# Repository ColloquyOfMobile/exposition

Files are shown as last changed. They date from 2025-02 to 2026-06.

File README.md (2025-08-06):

# exposition
Colloquy of Mobiles for exposition in ZKM

## Todo
In KiCad:
- Choose the footprint for power supply capacitor.
- Check dimension of jack barrel.

## Todo

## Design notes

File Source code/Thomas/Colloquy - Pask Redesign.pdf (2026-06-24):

ZKM | Zentrum für Kunst und Medien

# Gordon Pask – Colloquy of Mobiles

Redesign of 2018 Version

Thomas Erforth
23.6.2026

## Audio subsystem concept

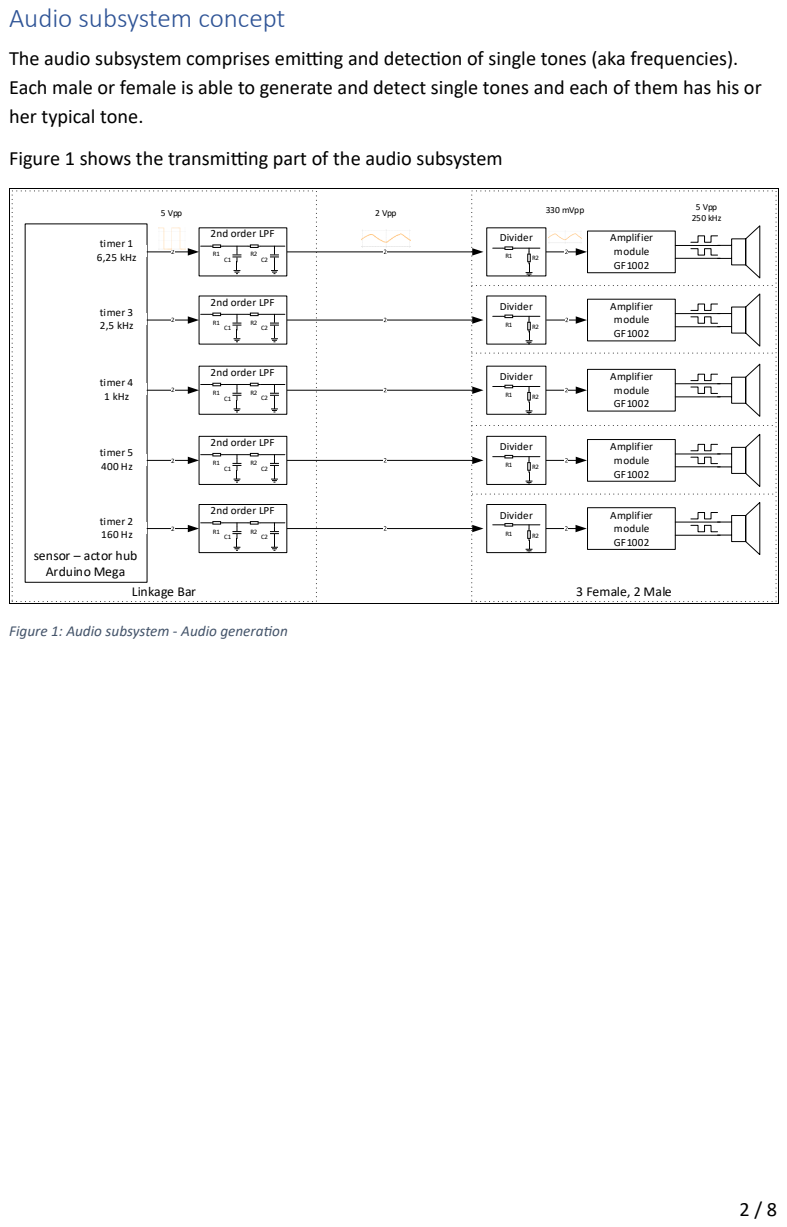
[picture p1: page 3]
timer 1 6,25 kHz; Amplifier module GF1002; timer 3 2,5 kHz; timer 4 1 kHz; timer 5 400 Hz; timer 2 160 Hz; 5 Vpp; 2 Vpp; 330 mVpp; Linkage Bar; 3 Female, 2 Male; 5 Vpp 250 kHz; 2nd order LPF; Divider

The audio subsystem comprises emitting and detection of single tones (aka frequencies).
Each male or female is able to generate and detect single tones and each of them has his or
her typical tone.

Figure 1 shows the transmitting part of the audio subsystem

sensor – actor hub
Arduino Mega

Figure 1: Audio subsystem - Audio generation

Figure 2 shows the receiving part of the audio subsystem

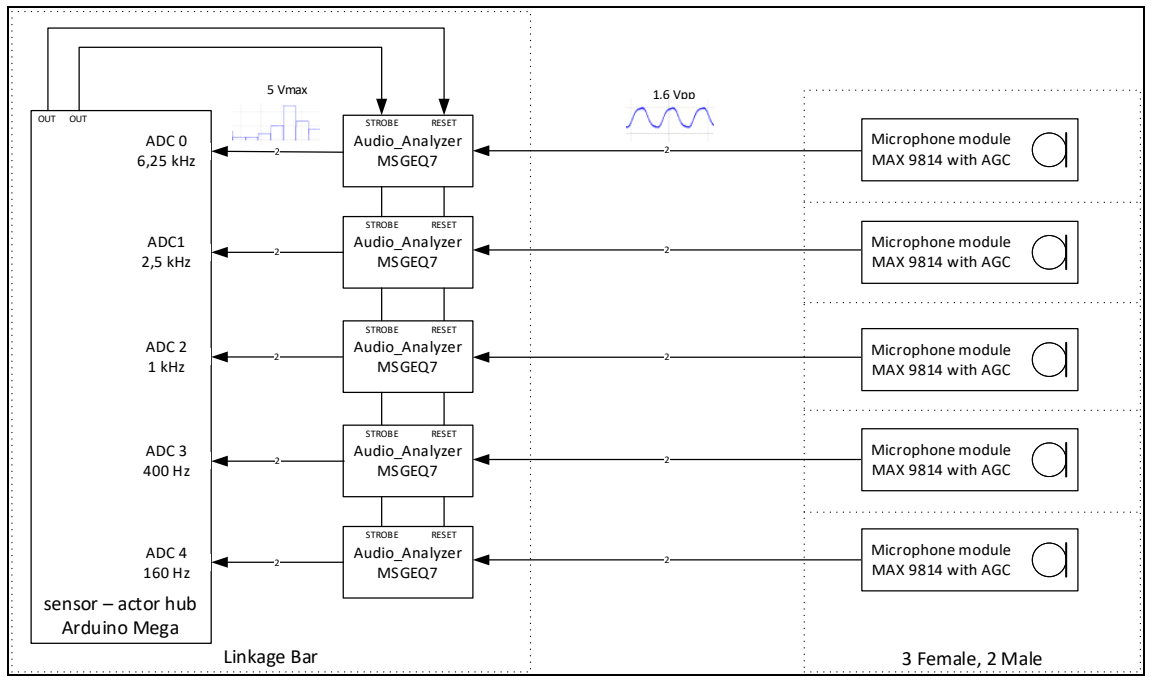
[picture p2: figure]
sensor – actor hub Arduino Mega; ADC 0 6,25 kHz; Audio_Analyzer MSGEQ7; Microphone module MAX 9814 with AGC; ADC1 2,5 kHz; ADC 2 1 kHz; ADC 3 400 Hz; ADC 4 160 Hz; 5 Vmax; 1,6 Vpp; Linkage Bar; 3 Female, 2 Male; STROBE; RESET; OUT

Figure 2: audio subsystem - Audio detection

In the following the structure of the audio subsystem and the design decisions are explained in more detail.

Audio generation and transmission

Tone generation
The audio analyzer module used for tone detection supports up to seven frequency bands: 63 Hz, 160 Hz, 400 Hz, 1KHz, 2.5 kHz, 6.25 kHz and 16 kHz.

Due to limitations in the frequency response of the components involved the 63 Hz and 16 kHz bands are of no choice. For example, typical electret microphones are specified in the frequency range of 100 Hz – 10000 Hz. And in addition, probably a significant amount of the audience will not even be able to hear the 16 kHz band anyway.

Since the ZKM concept uses a centralized sensor / actor hub the remaining five tones are generated by the Arduino Mega board. Timer 1, 3, 4, 5 (16-bit timers) and 2 (8-bit timer) are used for that purpose. With exception of the initialization, tone generation doesn’t consume computing power since all timers run independently in CTC mode.

Low Pass Filter
Generating tones by means of counters makes life easier but has a big drawback: The result has a rectangular shape. Square waves can be thought of as the superposition of sine waves, starting with the fundamental frequency plus all odd harmonics. Especially for the first three frequency bands the bandpass filters of the audio analyzer are not able to completely filter out the first harmonic, see Table 1. This makes it much more difficult to safely detect the incoming fundamental frequency, especially in a noisy environment.
Square wave freq. | 1 st harmonics | Neighbor band | Distance
160 Hz | 480 Hz | 400 Hz | 80 Hz
400 Hz | 1200 Hz | 1000 Hz | 200 Hz
1000 Hz | 3000 Hz | 2500 kHz | 500 Hz
2500 Hz | 7500 kHz | 6250k Hz | 1250 Hz
6250 Hz | 18750 Hz | 16000 Hz | 2750 Hz
Table 1: Frequency bands and their first harmonics

The best solution would be generating sine waves only. This is not feasible with the centralized computing concept since it will block the CPU of the hub during tone generation. Therefore, it has been decided to use simple passive 2nd order low pass filter stages to damp the first and subsequent harmonics sufficiently enough to improve the quality of the frequency detection. Figure 3 shows the principal diagram of the second order filter.

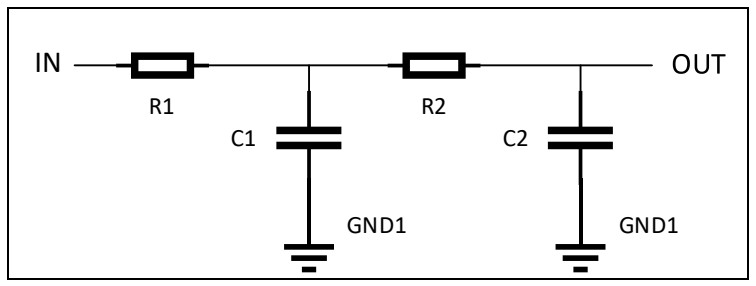
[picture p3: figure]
GND1

Figure 3: Passive 2nd order low pass filter

The output of the filter is still not a sine wave but measurements have shown the first harmonic damped by more than 20 dB = less than 10% to the fundamental frequency.

To simplify the design the two filter stages are identical, R1 = R2 and C1 = C2.

The following component values are used:

Band | R | C
6250 Hz | 2K2 | 10nF
2500 Hz | 1K8 | 47nF
1000 Hz | 1K2 | 150nF
400Hz | 2K | 220nF
160 Hz | 2K2 | 470nF
Table 2: Filter component values

It has been decided, while not necessarily needed for safe frequency detection, to add filter stages to the upper two frequency bands to achieve a more pleasant and uniform sound experience in all frequency bands.

Input divider
A potential divider is used to limit the filter output to the maximum allowed input level of the amplifier module when the volume control of the module is set to maximum level. The filter stages are dimensioned in a way to get identical component values for all five dividers: R1 / R2 = 22K / 3K3.

It is important never to exceed the maximum input level of the amplifier, otherwise it would go into clipping which results in a square wave output on the loudspeaker. This would render the filter stage useless.

Amplifier
The amplifier used is a GF 1002 module. It comes with volume level control included on the module which allows for further adjustments of the tone level later during field tests.

The amplifier is a class D design which means the output to the loudspeaker is formed by a differential PWM signal with approx. 250 kHz base frequency. The sharp edges and the high currents generate significant EMI emissions; therefore, the amplifier shall be placed close to the loudspeaker to keep the connection wires as short as possible.

Loudspeaker
The loudspeaker must be able to produce a flat frequency response over the range of 160 Hz up to 6250 Hz.

If the existing speakers fit the requirement needs to be tested. The speakers are mounted in an open frame and are working more or less in an acoustic short cut situation. Especially for the two lower frequencies it must be tested if the sound pressure is sufficient.

Audio detection

Microphone module
The 2018 version uses a microphone module with a simple OpAmp pre amplifier. There is a high probability that such a simple module will be overloaded in a noisy environment. The pre amplifier will go into saturation and output the tone as a square wave. Detecting the fundamental becomes unreliable as described before.

Instead, the concept foresees a microphone module with automatic gain control. Common modules carry the MAX9814. The device features a low-noise preamplifier, variable gain amplifier (VGA), output amplifier, microphone-bias-voltage generator and AGC control circuitry. AGC gives a lot more headroom to possible clipping situations.

In addition, the gain can be selected manually to 40dB, 50dB or 60dB. On the workbench best results were achieved with gain limited to 40dB and A/R ratio set to 1:500. With A/R ratio 1:500 the gain recovers fastest after spikes. Must be double checked in field.

Audio analyzer
The audio analyzer circuit MSGEQ7 has already been used in the 2018 version of the ‘Mobile’, so no change here.

Theoretically a small computing module could be used to perform a simple Fourier analysis however, implementing and debugging the code adds an additional level of complexity which would increase development time. With the described countermeasures of filtering and AGC it should be possible to reliably detect the fundamental frequency with the audio analyzer module.

The STROBE and RESET inputs of the audio analyzer modules are all connected together to spare port resources on the hub. One cycle over all seven bands will read the outputs of all modules at the same time. The analog outputs are connected to five ADC inputs of the hub.

One property of the MSGEQ7 must be considered during programming: The internal scan rate is fast enough to take dedicated samples from the curve of the 160 Hz and 400 Hz signals. So, continuous readings with a certain amount of time in-between will show varying results depending on which part of the signal shape has been measured. This problem could be solved by reading four times in short sequence when a 160 Hz signal and two times in a sequence when a 400 Hz signal is expected. The results for the 160 Hz input always showed at least two ‘hits’ of high input levels and the 400 Hz at least one. (Will need some more experiments in the field test.)

Prototype boards

For first tests some prototype boards have been designed. Figure 4 - Figure 7 show the pinout.

Low Pass Filter

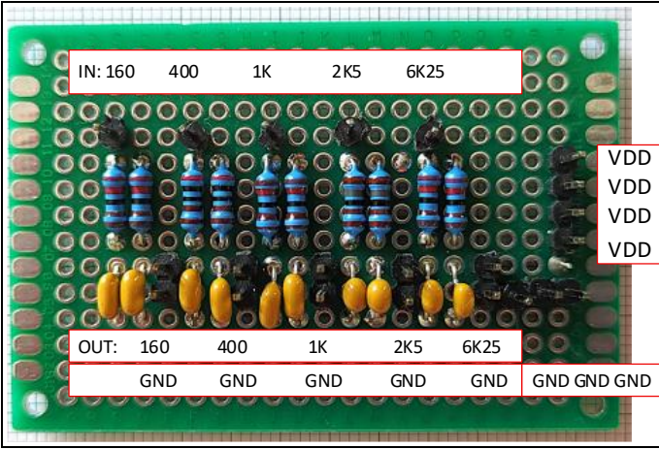
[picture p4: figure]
OUT: 160; GND; GND GND GND; VDD VDD VDD VDD

Figure 4: Filter module pinout

Microphone Module

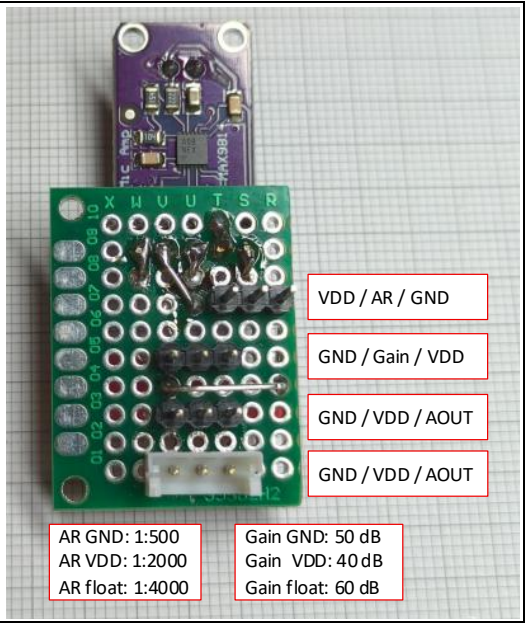
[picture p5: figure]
GND / VDD / AOUT; GND / Gain / VDD; VDD / AR / GND; AR GND: 1:500 AR VDD: 1:2000 AR float: 1:4000; Gain GND: 50 dB Gain VDD: 40 dB Gain float: 60 dB

Figure 5: Microphone module pinout

Amplifier Module

Audio
GND

Audio
VDD
GND

VDD
GND

ROUT+
ROUT-

ROUT+ / ROUT-

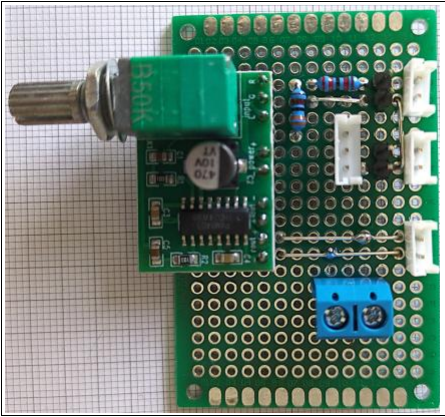
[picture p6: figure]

Figure 6: Amplifier module pinout

Audio Analyzer Array

AOUT

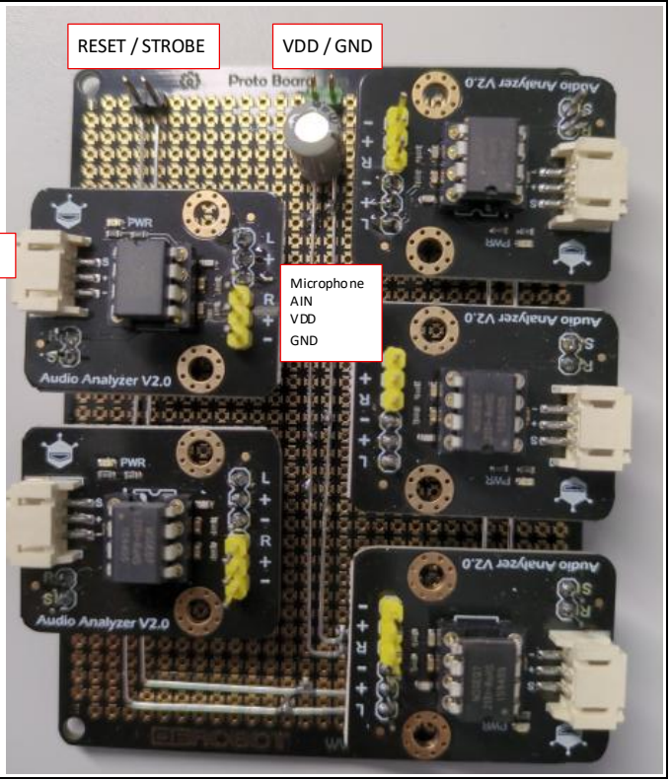
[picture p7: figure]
Microphone AIN VDD; GND; RESET / STROBE; VDD / GND

Figure 7: Audio analyzer array

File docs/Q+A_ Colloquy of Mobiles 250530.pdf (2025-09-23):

Q+A: Colloquy of Mobiles 250530
Victor, Morgan, Paul and TJ

### Question: Is the male/neopixel/ring always white ? (or matches drive color)

### Male neopixel ring color

The male has 2 neopixel rings. One displays drive level in white, this is above the unit and pointed toward the plinth. On system powerup, a reference pattern is briefly displayed across all neopixels that consists of a variety of colors. Once the system begins running, this neopixel ring is white and brightness varies.

The other is in the center of the unit and is white when searching, when it is reinforcing it has an animation one pixel of which shows drive state.

- Searching State - When the male is in a searching state, the NeoPixel ring appears white. This is determined by the act_update_drive_abso_light function, which sets the NeoPixel color to white when the drive state exceeds the other. For males, the brightness is set to a maximum of 128 when searching, resulting in a clear but not blinding white appearance.
- Reinforcing State - In contrast, during the reinforcing state, the NeoPixel ring animates to indicate the current drive state with a colored pixel. This is managed by the act_energy_driveanimation function, which illuminates one pixel to reflect the drive state—using orange for O and puce for P—while the remainder of the ring stays white and is set to maximum brightness.

Thomas J McLeish, May 30, 2025 page 1/9

### Question: How does drive level map to pixel brightness?

O drive max = 255 (max pixel brightness) ? O drive min = 0 (pixel shutdown) ? P drive max = 255 (max pixel brightness) ? P drive min = 0 (pixel shutdown) ?

### Perceptual Brightness Mapping for NeoPixels

The Colloquy of Mobiles 2018 implements perceptual brightness control for NeoPixels by mapping a linear input variable—drive level—to a non-linear brightness value that approximates the human eye’s response to light intensity. This is achieved through a fixed lookup table, allowing efficient real-time computation on resource-constrained microcontrollers.

Rationale

Human vision perceives brightness non-linearly. A linear increase in LED power does not result in a linear increase in perceived brightness. To address this, a non-linear brightness map is used, allowing small changes in brightness to be more noticeable in darker regions and less abrupt at higher intensities.

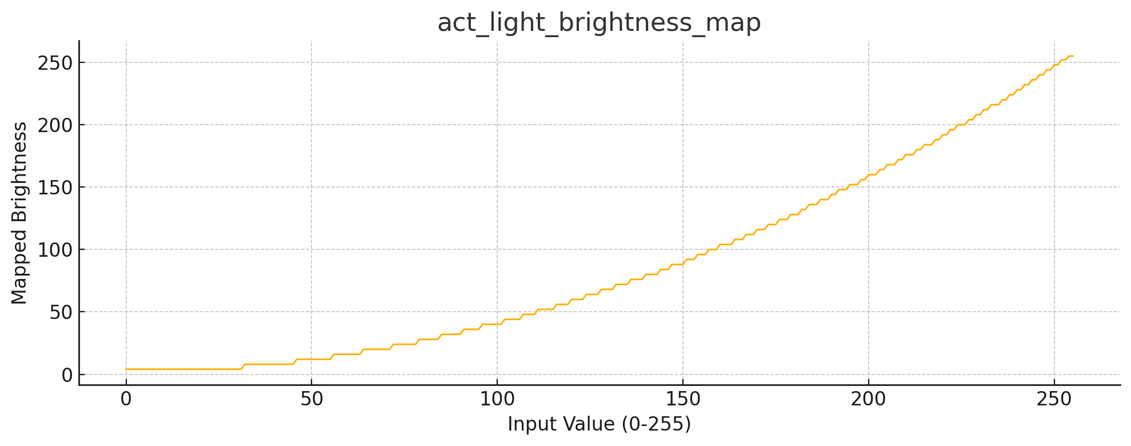
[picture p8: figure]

The human-perception brightness level is derived from an input value.

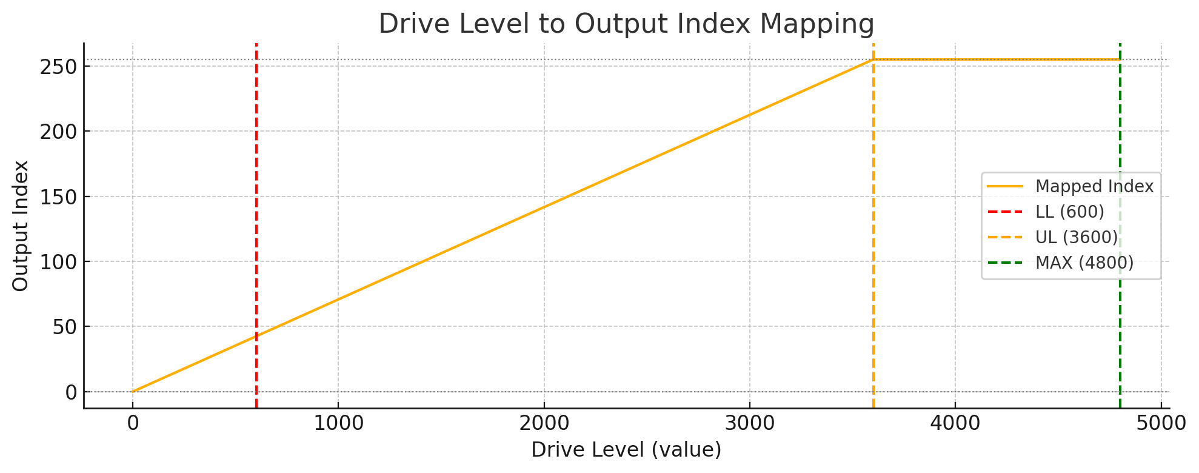
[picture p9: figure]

The input value is derived from the drive level.

See code:

// Drive level thresholds (in samples) const int internal_drive_LL = 600; // Low threshold (30 seconds)
const int internal_drive_UL = 3600; // High threshold (3 minutes)
const int internal_drive_MAX = 4800;
// Maximum (4 minutes)
const int internal_drive_adjustment_O = 1;
int | internal_drive_O = 0;
//set lights indicating
//level of O and P drive states act_update_O_light(constrain(map(internal _drive_O, 0, internal_drive_UL, 0, 255), 0, 255));
act_update_P_light(constrain(map(internal _drive_P, 0, internal_drive_UL, 0, 255), 0, 255));

### Question: What is the rate of drive level increment over time?

P drive increment X unit every Y seconds. X and Y ? O drive increment X unit every Y seconds. X and Y ?

### Drive Increment Rate per Time Unit

P drive increment: 1 unit every 50 ms
→ 20 units per second

O drive increment: 1 unit every 50 ms
→ 20 units per second
1. Sampling Interval:
- The system samples every 50 milliseconds, as defined by the variable time_sampleInterval.
- This results in 20 samples per second, calculated as follows:
■ 1000 milliseconds / 50 milliseconds = 20 samples per second.
2. Drive Increment:
- The increment for both the P and O drives is specified by the variables

### internal_drive_adjustment_P and internal_drive_adjustment_O, both of which

are set to 1.
- This means each drive increments by 1 unit for each sample.

In the code see:

const int | internal_drive_LL = 600; | //interested floor, in samples | 600 = 30 seconds
const int | internal_drive_UL = 3600; | //desperate floor, in samples | 3600 = 3 minutes
const int | internal_drive_MAX = 4800; | //in samples | 4800 = 4 minutes
const int | internal_drive_adjustment_O = 1;
const int | internal_drive_adjustment_P = 1;

### Question: How is drive level displayed on the units?

Show the female's drive on all the Neopixel or only on the top strip? On which Neopixel should I show the male drives ? (incoherence between video and documentation)

### NeoPixel Allocation and Drive Display Configuration (Female and Male Units)

Drive level is displayed across multiple sections of the neopixel strips. The Neopixel strips are utilized differently for female and male configurations, with each section assigned to represent various aspects of drive levels and indicators. Below is a comprehensive breakdown of how the Neopixels are organized:

Female Configuration

### 1. Drive Level Indicators - middle

- Indices 0 to 27: Represent the drive levels.
- Even Indices (0, 2, 4, ..., 26): Indicate the "P" drive level.
- Odd Indices (1, 3, 5, ..., 27): Indicate the "O" drive level.

### 2. Dominant Drive Display - bottom

- Indices 28 to 35: Highlight the dominant drive, either "O" or "P."

### 3. White Drive Level Indicator - top

- Indices 36 to 50: Display the drive level in white, ensuring a clear and distinct visual representation.

Male Configuration

### 1. Drive Level Display

- Indices 0 to 23: Show the drive level in white, providing a straightforward representation of the current drive status.

### 2. Center Ring for Search and Reinforcement

- Indices 24 to 47: Dedicated to the center ring, these indices are used for search and reinforcement.
- During reinforcement an animation is displayed wherein one pixel of the current drive state color spins around the ring.
- In the code see: act_energy_driveanimation

### 3. O and P Level Display

- Indices 48 to 55: Display the "O" level. Indices 56 to 63: Display the "P" level.

### Question: How many interactions are expected every hour ?

Female and Male Unit interaction rate.

The units have a variety of forms of interaction in their quest for satisfaction. The rate of interactions is non-deterministic as this is an agent based and self organizing system that is effected by ambient light, environmental noise, and crowd dynamics. Ideally there would be 6-12 satisfaction events per hour for the system.

1. The most frequent is the female repeating back to the male his search pattern in an audible tone. This happens when the female transitions from search to engaging with the male.
2. The next most frequent is the male hearing the sound and moving to his reinforcing position (if allowed by the bar). The male does not always hear the sound nor move into position quickly enough to adequately engage the female and so transitions back into searching.
3. The next most frequent is the reinforcement signal from the male to the female encouraging her to continue flapping her mirror. The female does not always hear this response due to environmental constraints.
4. The least frequent event is the satisfaction sequence performed by a unit when their drive level drops into the ‘satisfied’ threshold. It is this event that brings together the system into its most comprehensible state. This should happen at least once every 5-10 minutes, or 6-12 times an hour at the system level. This is based on assumptions about audience patience and engagement. It should be a magic and special moment worth waiting for for all, but not so rare that it is impossible for a visitor to spot.

### Question: Should the female start to flap the mirror immediately after sensing a male or should it sense the beam first?

Female transition to engaging with a partner.

Upon sensing a male with compatible drive interests the female transitions from searching for a partner to engaging with a partner. She immediately starts flapping her mirror and moves to her reinforcement position.

Sensing a male consists of sensing a light pattern from a male and matching it to her own internal drive pattern. If the patterns are compatible she has found a partner, if they are not she continues searching.

### Question: How do the male and female units use light and sound to communicate while searching and engaging?

What is the exact light pattern for the male while searching? What is the exact female sound pattern to notify a male that she is interested? What is the exact male encouragement sound pattern?

### Communication vocabulary and mediums

The male and female units use a fixed dictionary to communicate with each other. The dictionary consists of 8 words each with 40 segments, each corresponding to a system sample. The words provide the male identification and request. The requests are for engagement on O, P, either O or P, or reinforcement.

While searching, the males broadcast their identification and drive need using their intermittent signal lamp, the neopixel ring in the center of their body.

While searching, the females compare sensed light to their own drive need. If their need matches they repeat the signal in audio tones, white below corresponds to sound actuation and duration.

While engaging, the male broadcasts a reinforcement request in audio tones to encourage continued engagement.

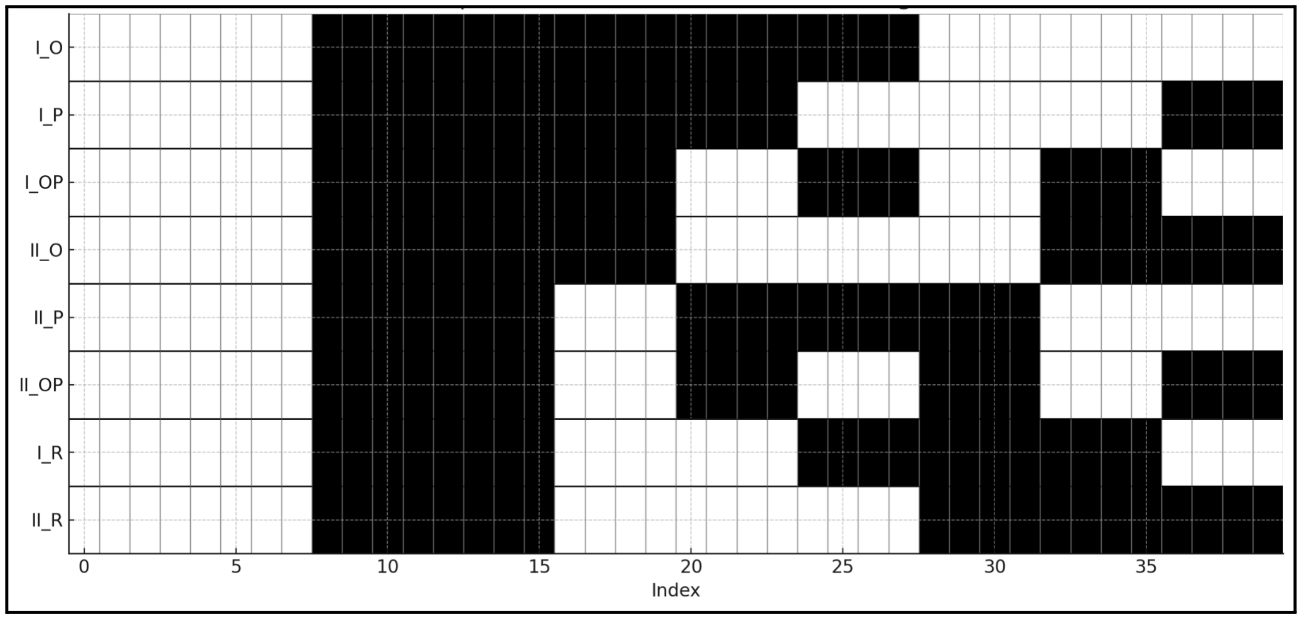
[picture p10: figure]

Communication Signal Dictionary
Each row is a fixed 40-segment pattern used to signal identity and drive need (light or sound ON = White).

See communication patterns in the code:

"I_O": [1,1,1,1,1,1,1,1,0,0,0,0,0,0,0,0,0,0,0,0,0,0,0,0,0,0,0,0,1,1,1,1,1,1,1,1,1,1,1,1], "I_P": [1,1,1,1,1,1,1,1,0,0,0,0,0,0,0,0,0,0,0,0,0,0,0,0,1,1,1,1,1,1,1,1,1,1,1,1,0,0,0,0], "I_OP": [1,1,1,1,1,1,1,1,0,0,0,0,0,0,0,0,0,0,0,0,1,1,1,1,0,0,0,0,1,1,1,1,0,0,0,0,1,1,1,1], "II_O": [1,1,1,1,1,1,1,1,0,0,0,0,0,0,0,0,0,0,0,0,1,1,1,1,1,1,1,1,1,1,1,1,0,0,0,0,0,0,0,0], "II_P": [1,1,1,1,1,1,1,1,0,0,0,0,0,0,0,0,1,1,1,1,0,0,0,0,0,0,0,0,0,0,0,0,1,1,1,1,1,1,1,1], "II_OP":[1,1,1,1,1,1,1,1,0,0,0,0,0,0,0,0,1,1,1,1,0,0,0,0,1,1,1,1,0,0,0,0,1,1,1,1,0,0,0,0], "I_R": [1,1,1,1,1,1,1,1,0,0,0,0,0,0,0,0,1,1,1,1,1,1,1,1,0,0,0,0,0,0,0,0,0,0,0,0,1,1,1,1], "II_R": [1,1,1,1,1,1,1,1,0,0,0,0,0,0,0,0,1,1,1,1,1,1,1,1,1,1,1,1,0,0,0,0,0,0,0,0,0,0,0,0],

I_O | → Male ID I, drive O
I_P | → Male ID I, drive P
I_OP | → Male ID I, drive O or P
II_O | → Male ID II, drive O
II_P | → Male ID II, drive P
II_OP → Male ID II, drive O or P
I_R | → Male I reinforcement signal
II_R | → Male II reinforcement signal

### Question: What is the satisfaction sequence implemented in the Colloquy of Mobiles

2018?

What is the exact climax light and sound pattern for the female ?
What is the exact climax light and sound pattern for the male ?

### Satisfaction sequence and mode for Male and Female Units

Once satisfaction is achieved, the units exhibit a display before transitioning into the satisfied state. The specific performance is dependent on the unit type and the partner with which satisfaction was reached. The female responds in light, the male responds in sound. Some refer to this as the ‘climax’, this term was not used by Pask in “A COMMENT, A CASE HISTORY, AND A PLAN”.

int act_satisfaction_index = 0;
//the satisfaction sequence consists of 14 segments
const int act_satisfaction_Count = 14;
//male sound tone sequence
const int act_satisfaction_vals[15] = {80, 160, 80, 551, 80, 926, 2300, 3700, 2300, 3700, 2300, 3700, 2300, 3700, 2300};
//tone or light pattern durations in system samples for both male and female
const int act_satisfaction_Durations_II[15] = {10, 5, 10, 5, 10, 5, 10, 10, 10, 10, 5, 5, 5, 5, 15}; //incrementing through the arrays to set duration and action
act_satisfaction_Duration = act_satisfaction_Durations_II[act_satisfaction_index];
//for female
FEMALE_reinforcement_animation_brightness = (timer_satisfactionanimation * 256) / act_satisfaction_Duration;
act_reinforcement_O(FEMALE_reinforcement_animation_brightness);//a uniform brightness pulse on NeoPixels
//for male
tone(act_audio_pwm_pin, act_satisfaction_vals[act_satisfaction_index]);

### Question: Is the ‘memory’ described in Pask’s original documents implemented in the Colloquy of Mobiles 2018?

Does the mirror has a search state when the female doesn't remember the male ? (search state would be stop when the encouragement signal is heard.)

Does the male confirmation sound hold informations about the drive ? (for the female to memorize the position of the drive)

Looks the memorization feature is commented out in TJ's code … Is the memorization actually feasible ? (On a first look, it seems that some more information should be passed from the male to the female)

### Implementation and Feasibility of Memory in Colloquy of Mobiles 2018

No. The memory mechanism described in Pask’s original documents was not implemented in Colloquy of Mobiles 2018. It was found to be extremely difficult to recreate and debug, testing that was done suggested it was improbable that satisfaction could ever occur if memory was implemented as suggest in the original documents. There may be an error in the diagram that led to broken and malformed logic.

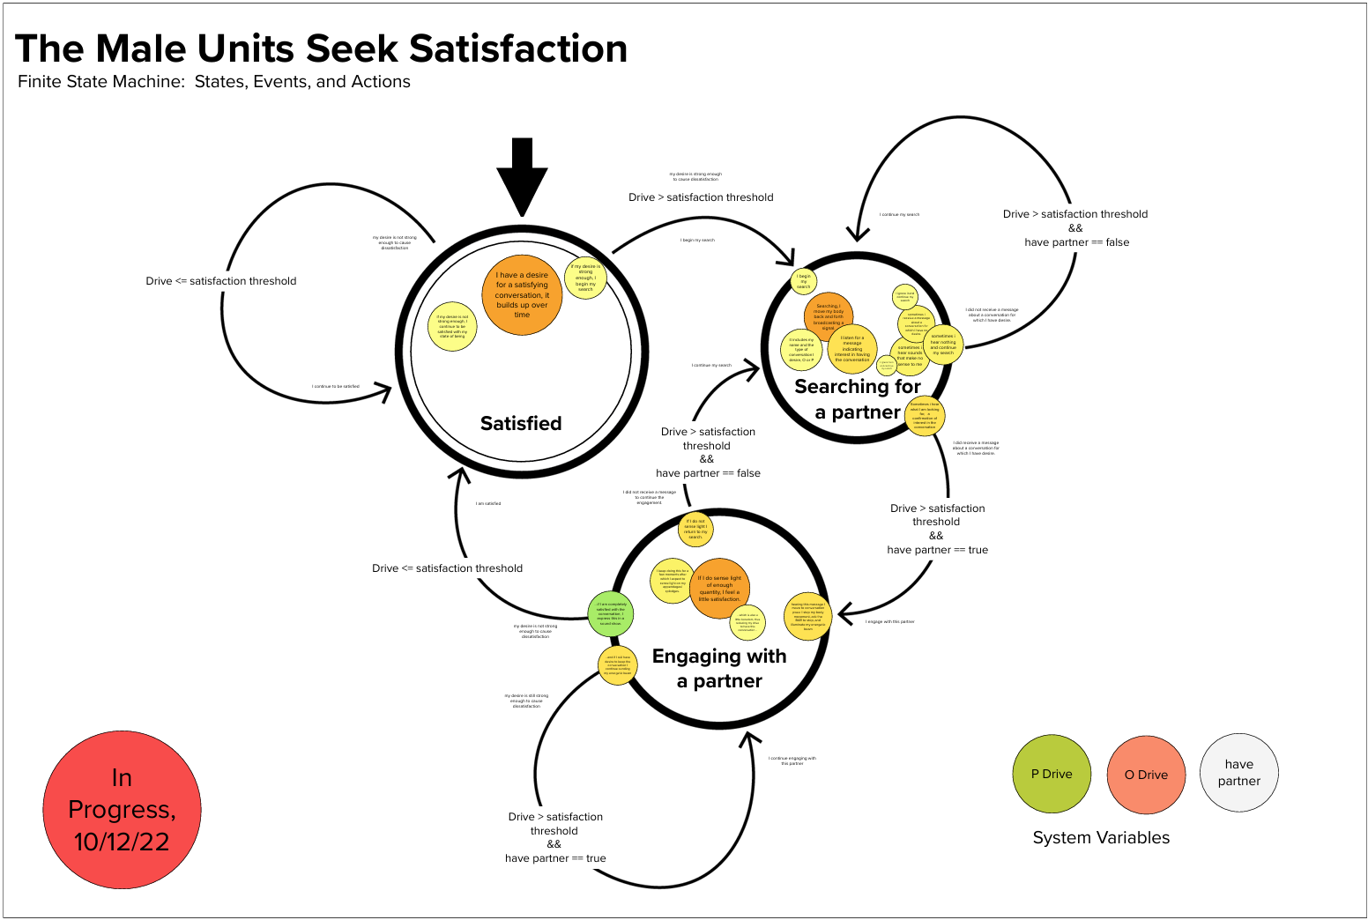
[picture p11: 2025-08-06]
CAD/Blender/male state diagram.png

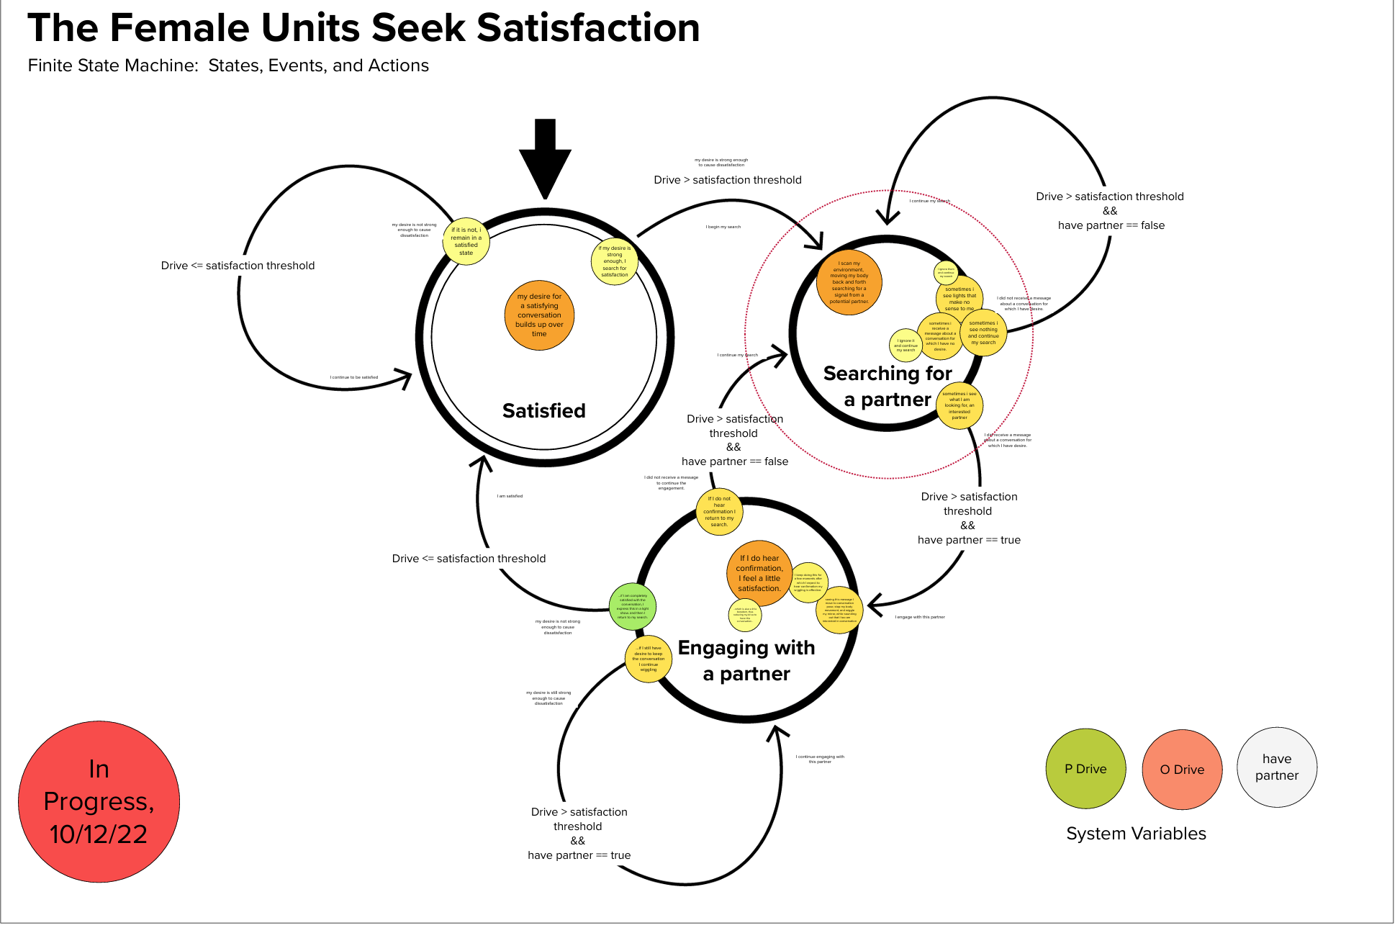
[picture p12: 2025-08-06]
CAD/Blender/female state diagram.png

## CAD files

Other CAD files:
CAD/Freecad/male static edge cut.FCStd
CAD/Freecad/center edge cut.FCStd
CAD/Freecad/electronic box edge cut.FCStd
CAD/Freecad/female base edge cut.FCStd
CAD/Freecad/female static edge cut.FCStd
CAD/Blender/scenarios.blend
CAD/Blender/video analysis.blend
CAD/Freecad/center edge cut.dxf
CAD/Freecad/electronic box edge cut.dxf
CAD/Freecad/female base edge cut.dxf
CAD/Freecad/female static edge cut.dxf
CAD/Freecad/male static edge cut.dxf

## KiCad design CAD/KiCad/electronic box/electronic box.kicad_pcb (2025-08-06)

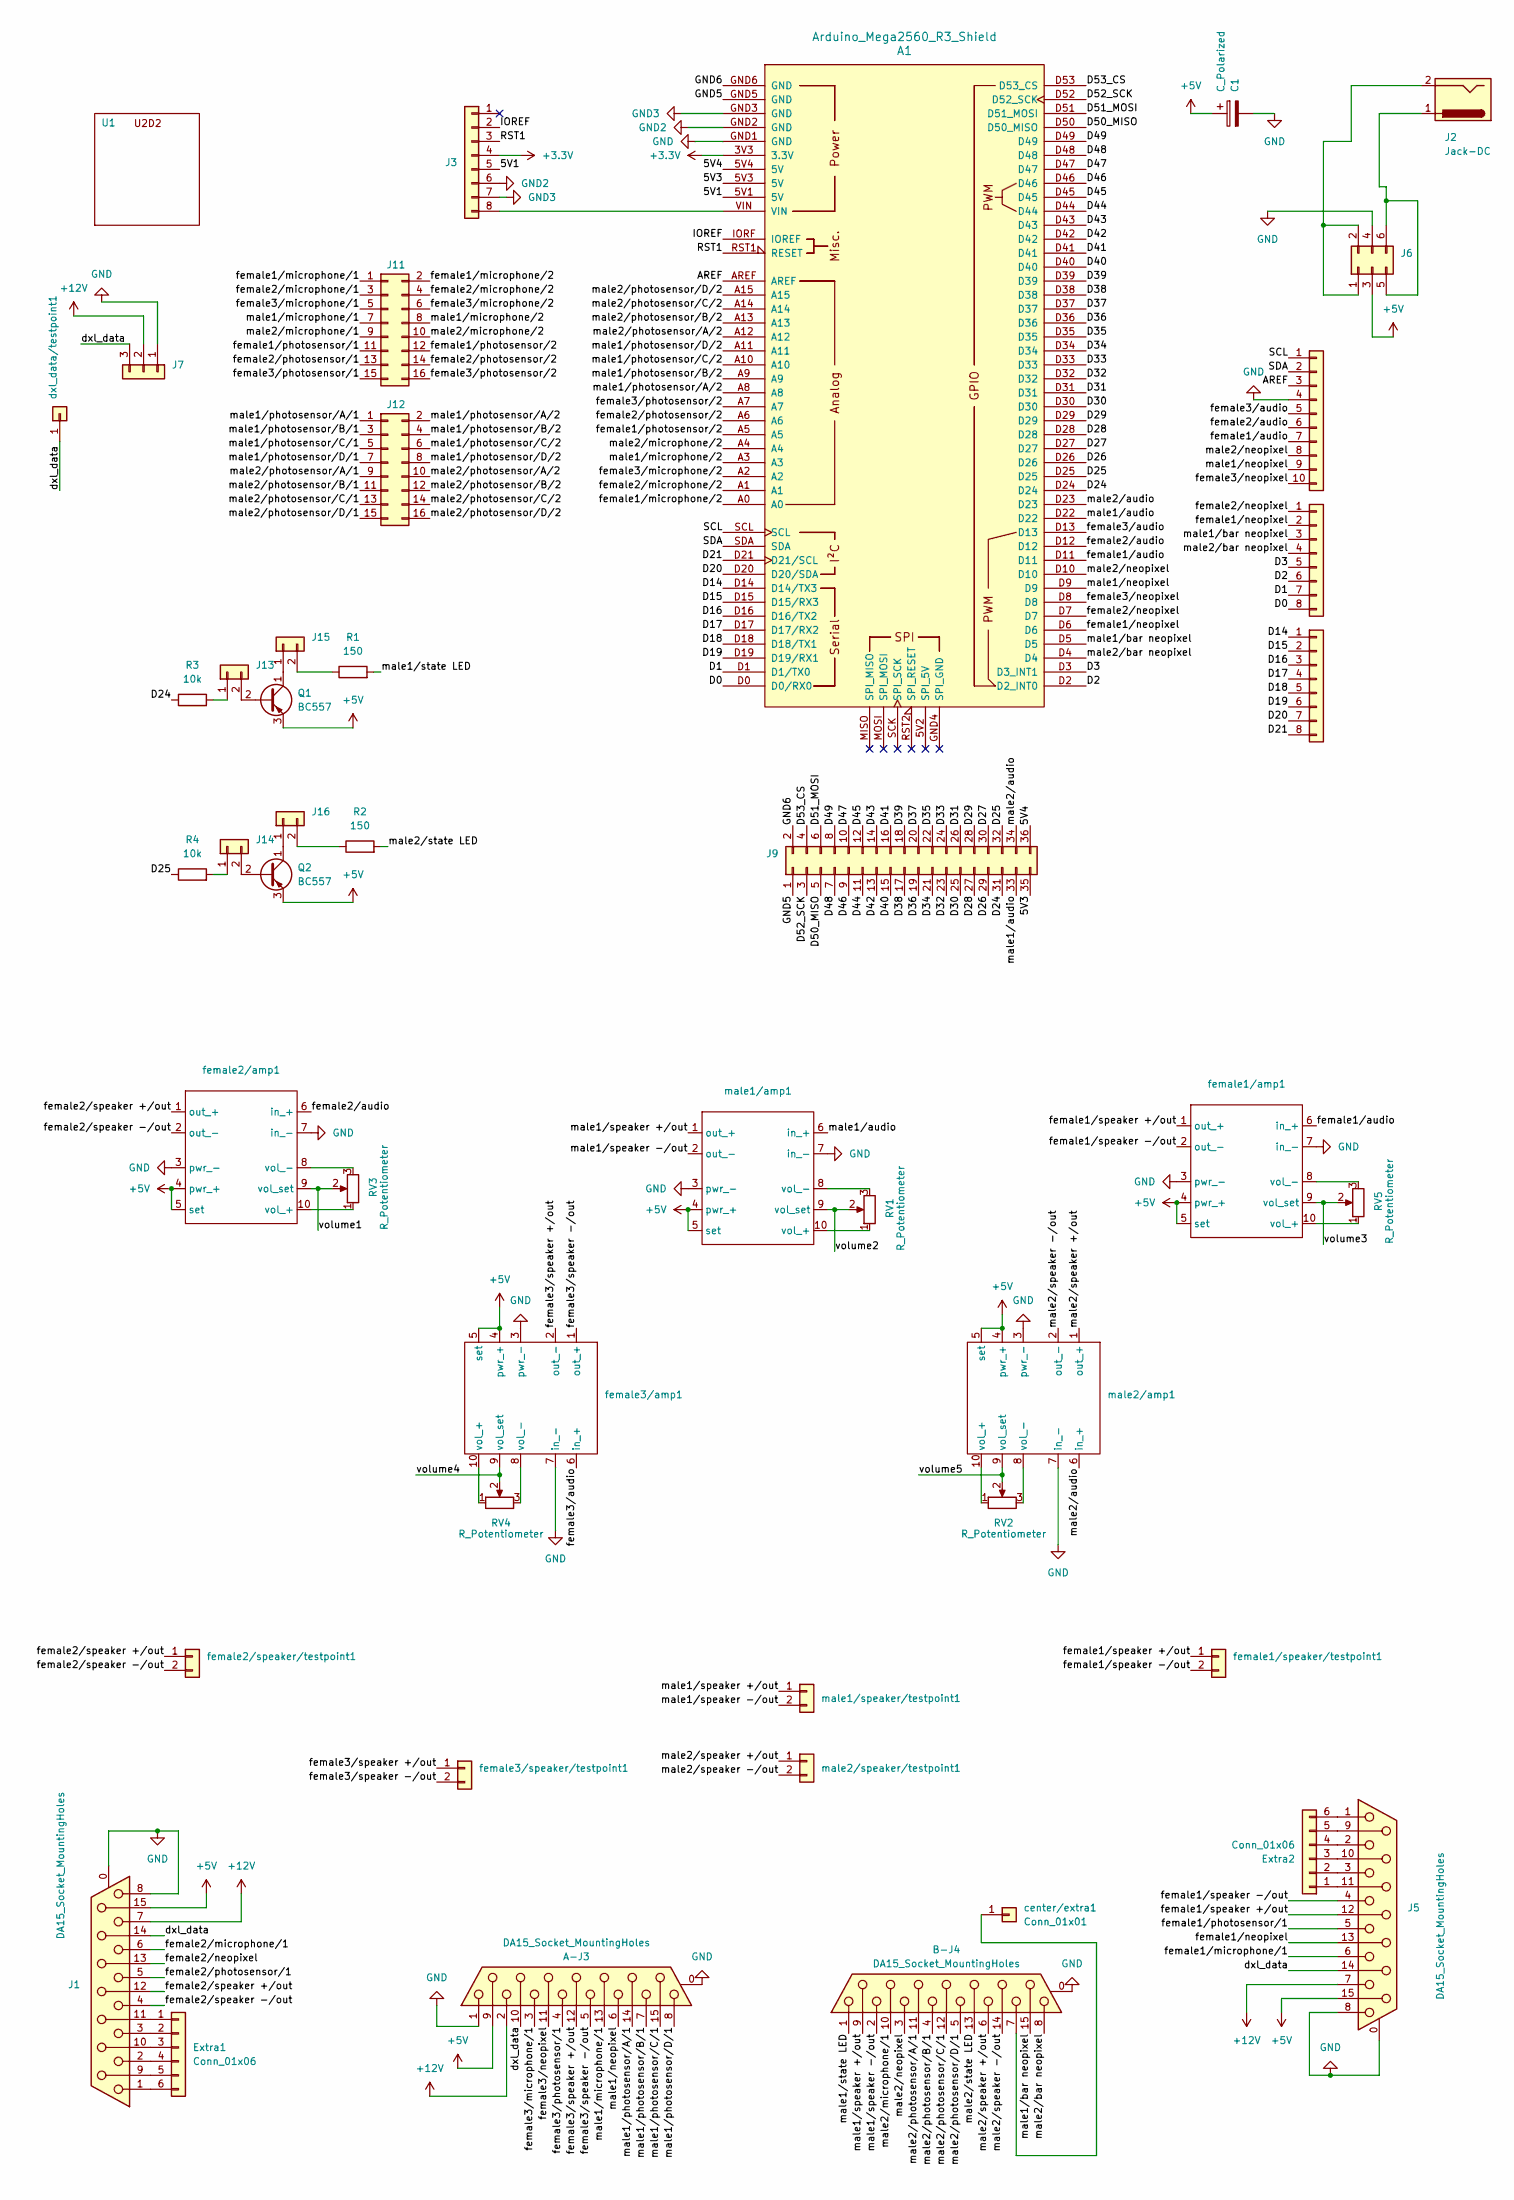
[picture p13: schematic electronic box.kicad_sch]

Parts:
A1: Arduino_Mega2560_R3_Shield
A-J3: DA15_Socket_MountingHoles; DSUB-15_Pins_Horizontal_P2.77x2.84mm_EdgePinOffset4.94mm_Ho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
B-J4: DA15_Socket_MountingHoles; DSUB-15_Pins_Horizontal_P2.77x2.84mm_EdgePinOffset4.94mm_Ho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
C1: C_Polarized; CP_Radial_D13.0mm_P5.00mm
Extra1, Extra2: Conn_01x06; PinHeader_1x06_P2.54mm_Vertical
J1, J5: DA15_Socket_MountingHoles; DSUB-15_Pins_Horizontal_P2.77x2.84mm_EdgePinOffset4.94mm_Ho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
J2: Jack-DC; PJ-082BH jack 10A
J3: Conn_01x06; PinHeader_1x08_P2.54mm_Vertical
J4: Conn_01x10; PinHeader_1x10_P2.54mm_Vertical
J6: Conn_02x03_Counter_Clockwise; screw brigde
J7: Conn_01x03; JST_EH_B3B-EH-A_1x03_P2.50mm_Vertical
J8, J10: Conn_01x08; PinHeader_1x08_P2.54mm_Vertical
J9: Conn_02x18_Odd_Even; PinHeader_2x18_P2.54mm_Vertical
J11, J12: Conn_02x08_Odd_Even; PinHeader_2x08_P2.54mm_Vertical
J13, J14, J15, J16: Conn_01x02; PinHeader_1x02_P2.54mm_Vertical
Q1, Q2: BC557; TO-92_Inline
R1, R2: 150; R_Axial_DIN0207_L6.3mm_D2.5mm_P10.16mm_Horizontal
R3, R4: 10k; R_Axial_DIN0207_L6.3mm_D2.5mm_P10.16mm_Horizontal
RV1, RV2, RV3, RV4, RV5: R_Potentiometer; custom potentiometer 1
U1: u2d2_mounting
center/extra1: Conn_01x01; PinHeader_1x01_P1.00mm_Vertical
dxl_data/testpoint1: Conn_01x01; PinHeader_1x01_P1.00mm_Vertical
female1/amp1, female2/amp1, female3/amp1: SparkFun Mono Audio Amp Breakout TPA2005D1
female1/speaker/testpoint1, female2/speaker/testpoint1, female3/speaker/testpoint1: Conn_01x01; PinHeader_1x02_P2.54mm_Vertical
male1/amp1, male2/amp1: SparkFun Mono Audio Amp Breakout TPA2005D1
male1/speaker/testpoint1, male2/speaker/testpoint1: Conn_01x01; PinHeader_1x02_P2.54mm_Vertical

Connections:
+3.3V: A1.3V3 (3.3V), J3.4
+5V: A-J3.9, C1.1, J1.15, J5.15, J6.3, Q1.3 (E), Q2.3 (E), female1/amp1.4 (pwr_+), female1/amp1.5 (set), female2/amp1.4 (pwr_+), female2/amp1.5 (set), female3/amp1.4 (pwr_+), female3/amp1.5 (set), male1/amp1.4 (pwr_+), male1/amp1.5 (set), male2/amp1.4 (pwr_+), male2/amp1.5 (set)
+12V: A-J3.2, J1.7, J5.7, J7.2
/5V1: A1.5V1 (5V), J3.5
/5V3: A1.5V3 (5V), J9.35
/5V4: A1.5V4 (5V), J9.36
/AREF: A1.AREF, J4.3
/D0: A1.D0 (D0/RX0), J8.8
/D1: A1.D1 (D1/TX0), J8.7
/D2: A1.D2 (D2_INT0), J8.6
/D3: A1.D3 (D3_INT1), J8.5
/D14: A1.D14 (D14/TX3), J10.1
/D15: A1.D15 (D15/RX3), J10.2
/D16: A1.D16 (D16/TX2), J10.3
/D17: A1.D17 (D17/RX2), J10.4
/D18: A1.D18 (D18/TX1), J10.5
/D19: A1.D19 (D19/RX1), J10.6
/D20: A1.D20 (D20/SDA), J10.7
/D21: A1.D21 (D21/SCL), J10.8
/D24: A1.D24, J9.31, R3.1
/D25: A1.D25, J9.32, R4.1
/D26: A1.D26, J9.29
/D27: A1.D27, J9.30
/D28: A1.D28, J9.27
/D29: A1.D29, J9.28
/D30: A1.D30, J9.25
/D31: A1.D31, J9.26
/D32: A1.D32, J9.23
/D33: A1.D33, J9.24
/D34: A1.D34, J9.21
/D35: A1.D35, J9.22
/D36: A1.D36, J9.19
/D37: A1.D37, J9.20
/D38: A1.D38, J9.17
/D39: A1.D39, J9.18
/D40: A1.D40, J9.15
/D41: A1.D41, J9.16
/D42: A1.D42, J9.13
/D43: A1.D43, J9.14
/D44: A1.D44, J9.11
/D45: A1.D45, J9.12
/D46: A1.D46, J9.9
/D47: A1.D47, J9.10
/D48: A1.D48, J9.7
/D49: A1.D49, J9.8
/D50_MISO: A1.D50 (D50_MISO), J9.5
/D51_MOSI: A1.D51 (D51_MOSI), J9.6
/D52_SCK: A1.D52 (D52_SCK), J9.3
/D53_CS: A1.D53 (D53_CS), J9.4
/GND5: A1.GND5 (GND), J9.1
/GND6: A1.GND6 (GND), J9.2
/IOREF: A1.IORF (IOREF), J3.2
/RST1: A1.RST1 (RESET), J3.3
/SCL: A1.SCL, J4.1
/SDA: A1.SDA, J4.2
/dxl_data: A-J3.10, J1.14, J5.14, J7.3, dxl_data/testpoint1.1
/female1/audio: A1.D11, J4.7, female1/amp1.6 (in_+)
/female1/microphone/1: J5.6, J11.1
/female1/microphone/2: A1.A0, J11.2
/female1/neopixel: A1.D6, J5.13, J8.2
/female1/photosensor/1: J5.5, J11.11
/female1/photosensor/2: A1.A5, J11.12
/female1/speaker +/out: J5.12, female1/amp1.1 (out_+), female1/speaker/testpoint1.1
/female1/speaker -/out: J5.4, female1/amp1.2 (out_-), female1/speaker/testpoint1.2
/female2/audio: A1.D12, J4.6, female2/amp1.6 (in_+)
/female2/microphone/1: J1.6, J11.3
/female2/microphone/2: A1.A1, J11.4
/female2/neopixel: A1.D7, J1.13, J8.1
/female2/photosensor/1: J1.5, J11.13
/female2/photosensor/2: A1.A6, J11.14
/female2/speaker +/out: J1.12, female2/amp1.1 (out_+), female2/speaker/testpoint1.1
/female2/speaker -/out: J1.4, female2/amp1.2 (out_-), female2/speaker/testpoint1.2
/female3/audio: A1.D13, J4.5, female3/amp1.6 (in_+)
/female3/microphone/1: A-J3.3, J11.5
/female3/microphone/2: A1.A2, J11.6
/female3/neopixel: A1.D8, A-J3.11 (P111), J4.10
/female3/photosensor/1: A-J3.4, J11.15
/female3/photosensor/2: A1.A7, J11.16
/female3/speaker +/out: A-J3.12, female3/amp1.2 (out_-), female3/speaker/testpoint1.1
/female3/speaker -/out: A-J3.5, female3/amp1.1 (out_+), female3/speaker/testpoint1.2
/male1/audio: A1.D22, J9.33, male1/amp1.6 (in_+)
/male1/bar neopixel: A1.D5, B-J4.15, J8.3
/male1/microphone/1: A-J3.13, J11.7
/male1/microphone/2: A1.A3, J11.8
/male1/neopixel: A1.D9, A-J3.6, J4.9
/male1/photosensor/A/1: A-J3.14, J12.1
/male1/photosensor/A/2: A1.A8, J12.2
/male1/photosensor/B/1: A-J3.7, J12.3
/male1/photosensor/B/2: A1.A9, J12.4
/male1/photosensor/C/1: A-J3.15, J12.5
/male1/photosensor/C/2: A1.A10, J12.6
/male1/photosensor/D/1: A-J3.8, J12.7
/male1/photosensor/D/2: A1.A11, J12.8
/male1/speaker +/out: B-J4.9, male1/amp1.1 (out_+), male1/speaker/testpoint1.1
/male1/speaker -/out: B-J4.2, male1/amp1.2 (out_-), male1/speaker/testpoint1.2
/male1/state LED: B-J4.1, R1.2
/male2/audio: A1.D23, J9.34, male2/amp1.6 (in_+)
/male2/bar neopixel: A1.D4, B-J4.8, J8.4
/male2/microphone/1: B-J4.10, J11.9
/male2/microphone/2: A1.A4, J11.10
/male2/neopixel: A1.D10, B-J4.3, J4.8
/male2/photosensor/A/1: B-J4.11 (P111), J12.9
/male2/photosensor/A/2: A1.A12, J12.10
/male2/photosensor/B/1: B-J4.4, J12.11
/male2/photosensor/B/2: A1.A13, J12.12
/male2/photosensor/C/1: B-J4.12, J12.13
/male2/photosensor/C/2: A1.A14, J12.14
/male2/photosensor/D/1: B-J4.5, J12.15
/male2/photosensor/D/2: A1.A15, J12.16
/male2/speaker +/out: B-J4.6, male2/amp1.1 (out_+), male2/speaker/testpoint1.1
/male2/speaker -/out: B-J4.14, male2/amp1.2 (out_-), male2/speaker/testpoint1.2
/male2/state LED: B-J4.13, R2.2
/volume1: RV3.2, female2/amp1.9 (vol_set)
/volume2: RV1.2, male1/amp1.9 (vol_set)
/volume3: RV5.2, female1/amp1.9 (vol_set)
/volume4: RV4.2, female3/amp1.9 (vol_set)
/volume5: RV2.2, male2/amp1.9 (vol_set)
GND: A1.GND1 (GND), A-J3.0 (PAD), A-J3.1, B-J4.0 (PAD), C1.2, J1.0 (PAD), J1.8, J4.4, J5.0 (PAD), J5.8, J6.4, J7.1, female1/amp1.3 (pwr_-), female1/amp1.7 (in_-), female2/amp1.3 (pwr_-), female2/amp1.7 (in_-), female3/amp1.3 (pwr_-), female3/amp1.7 (in_-), male1/amp1.3 (pwr_-), male1/amp1.7 (in_-), male2/amp1.3 (pwr_-), male2/amp1.7 (in_-)
GND2: A1.GND2 (GND), J3.6
GND3: A1.GND3 (GND), J3.7
unnamed: Extra1.1, J1.11 (P111)
unnamed: Extra1.2, J1.3
unnamed: Extra1.3, J1.10
unnamed: Extra1.4, J1.2
unnamed: Extra1.5, J1.9
unnamed: Extra1.6, J1.1
unnamed: Extra2.1, J5.11 (P111)
unnamed: Extra2.2, J5.3
unnamed: Extra2.3, J5.10
unnamed: Extra2.4, J5.2
unnamed: Extra2.5, J5.9
unnamed: Extra2.6, J5.1
unnamed: A1.VIN, J3.8
unnamed: J2.2, J6.1, J6.2
unnamed: J2.1, J6.5, J6.6
unnamed: J13.1, R3.2
unnamed: J13.2, Q1.2 (B)
unnamed: J14.1, R4.2
unnamed: J14.2, Q2.2 (B)
unnamed: J15.1, Q1.1 (C)
unnamed: J15.2, R1.1
unnamed: J16.1, Q2.1 (C)
unnamed: J16.2, R2.1
unnamed: B-J4.7, center/extra1.1
unnamed: RV5.1, female1/amp1.10 (vol_+)
unnamed: RV5.3, female1/amp1.8 (vol_-)
unnamed: RV3.1, female2/amp1.10 (vol_+)
unnamed: RV3.3, female2/amp1.8 (vol_-)
unnamed: RV4.1, female3/amp1.10 (vol_+)
unnamed: RV4.3, female3/amp1.8 (vol_-)
unnamed: RV1.1, male1/amp1.10 (vol_+)
unnamed: RV1.3, male1/amp1.8 (vol_-)
unnamed: RV2.1, male2/amp1.10 (vol_+)
unnamed: RV2.3, male2/amp1.8 (vol_-)

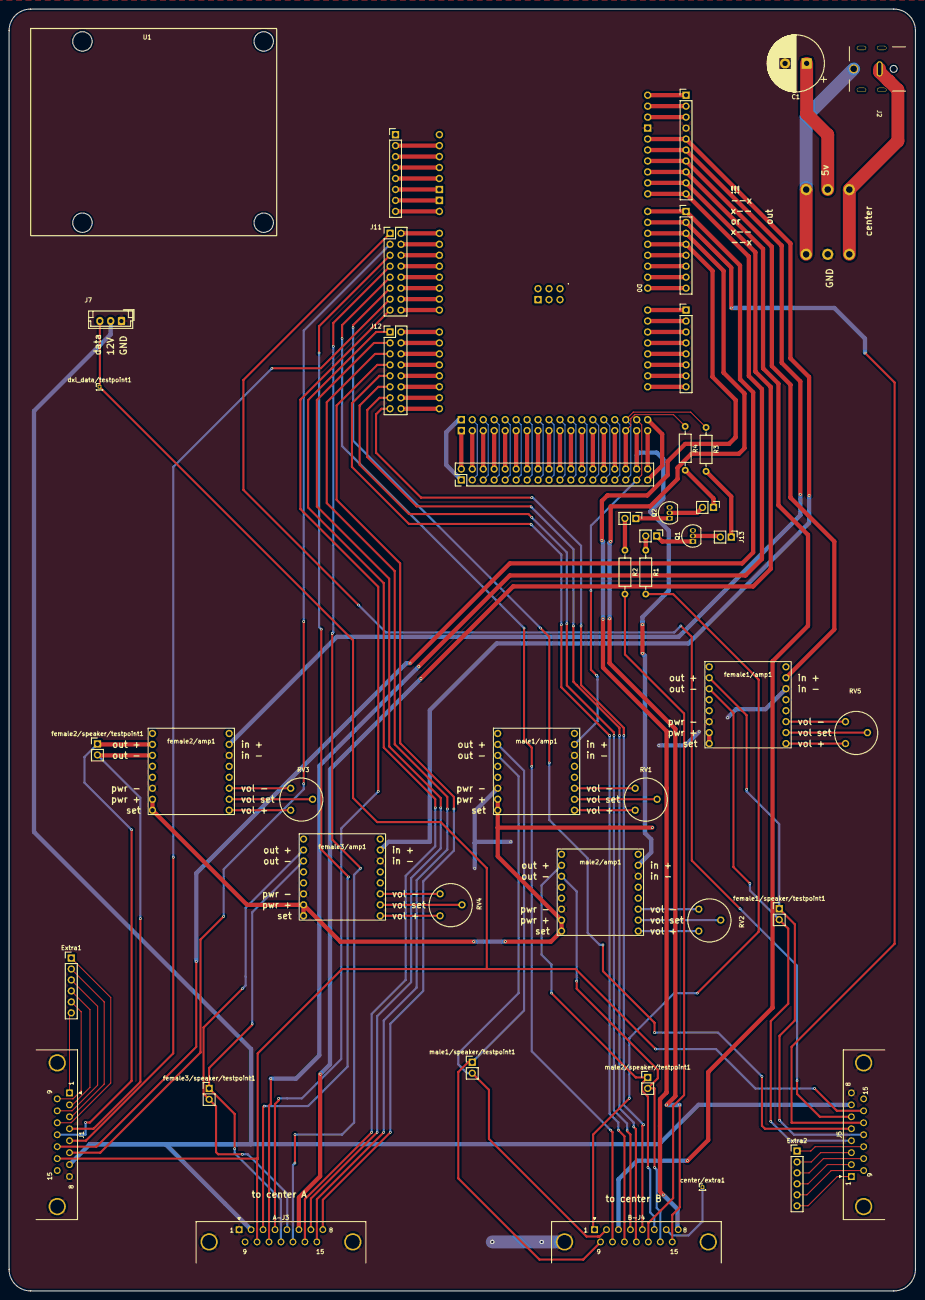
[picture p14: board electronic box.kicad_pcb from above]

Board: 2 copper layers, 210.0 x 297.0 mm, 46 parts (0 on the bottom side), 154 nets.

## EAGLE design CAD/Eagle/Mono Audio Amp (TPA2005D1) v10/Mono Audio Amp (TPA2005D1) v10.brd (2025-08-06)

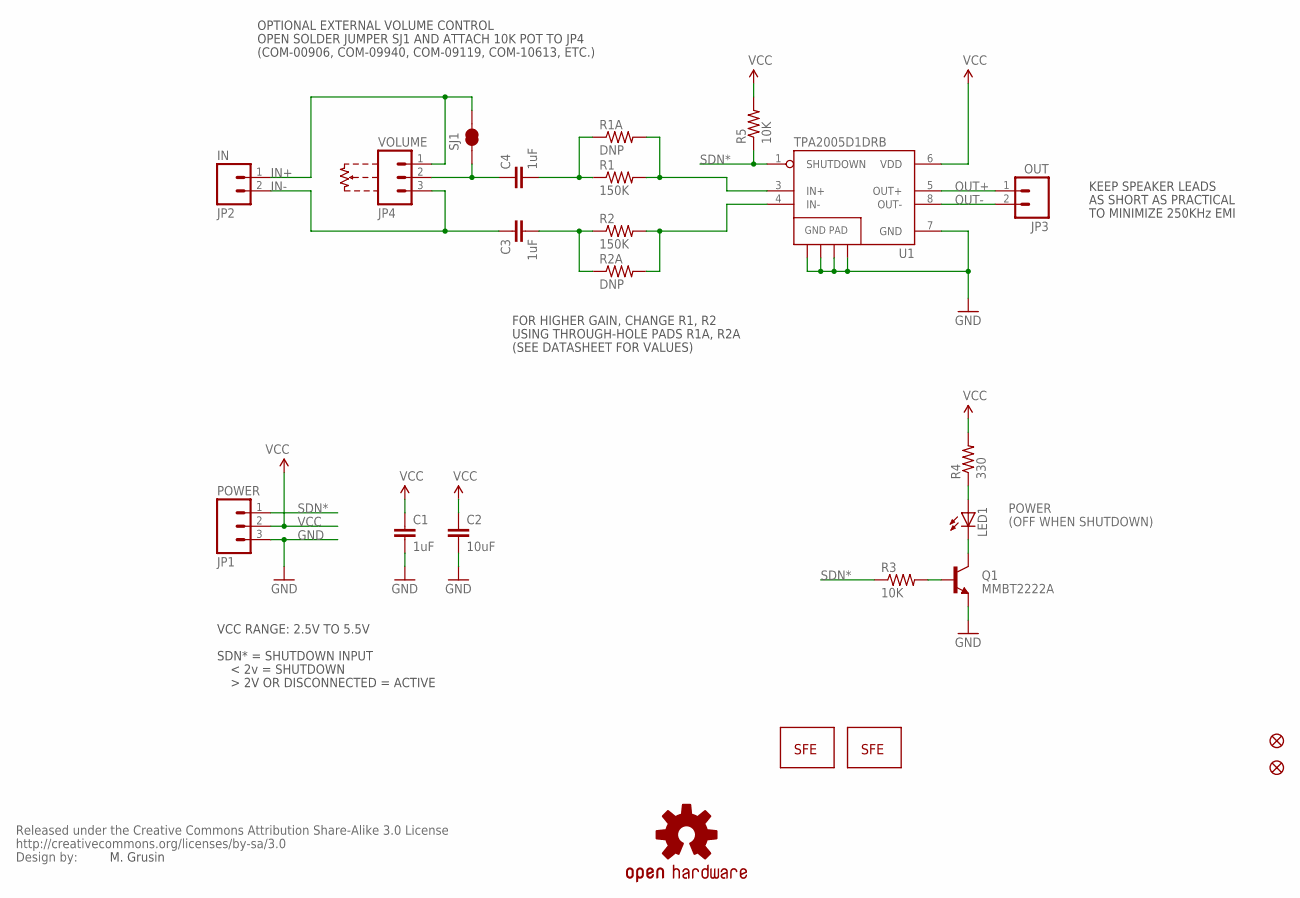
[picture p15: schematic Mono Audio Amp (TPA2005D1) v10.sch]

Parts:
C1, C3, C4: 1uF; 1206
C2: 10uF; 1206
JP1: POWER; 1X03
JP2: IN; 1X02
JP3: OUT; 1X02
JP4: VOLUME; 1X03
JP5, JP6: FIDUCIALUFIDUCIAL; MICRO-FIDUCIAL
LED1: LED0603; LED-0603
LOGO1: LOGO-SFENW2; SFE-NEW-WEB
LOGO2: LOGO-SFESK; SFE-LOGO-FLAME
Q1: MMBT2222A; SOT23-3
R1, R2: 150K; 0603-RES
R1A, R2A: DNP; AXIAL-0.3
R3, R5: 10K; 0603-RES
R4: 330; 0603-RES
SJ1: SOLDERJUMPERNC2; SJ_2S-NOTRACE
U1: TPA2005D1DRB; QFN-8_PAD
U$1: CREATIVE_COMMONS
U$2: OSHW-LOGOS; OSHW-LOGO-S

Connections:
GND: C1.2, C2.2, JP1.3, Q1.2 (E), U1.7 (GND), U1.10 (GND), U1.11 (GND), U1.12 (GND), U1.13 (GND)
IN+: JP2.1, JP4.1, SJ1.2
IN+AMP: R1.2, R1A.P$2 (2), U1.3 (IN+)
IN-: C3.1, JP2.2, JP4.3
IN-AMP: R2.2, R2A.P$2 (2), U1.4 (IN-)
unnamed: C4.1, JP4.2, SJ1.1
unnamed: C4.2, R1.1, R1A.P$1 (1)
unnamed: C3.2, R2.1, R2A.P$1 (1)
unnamed: LED1.C, Q1.3 (C)
unnamed: LED1.A, R4.1
unnamed: Q1.1 (B), R3.2
OUT+: JP3.1, U1.5 (OUT+)
OUT-: JP3.2, U1.8 (OUT-)
SDN*: JP1.1, R3.1, R5.1, U1.1 (SHUTDOWN)
VCC: C1.1, C2.1, JP1.2, R4.2, R5.2, U1.6 (VDD)

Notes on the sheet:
POWER
(OFF WHEN SHUTDOWN)
OPEN SOLDER JUMPER SJ1 AND ATTACH 10K POT TO JP4
OPTIONAL EXTERNAL VOLUME CONTROL
M. Grusin
FOR HIGHER GAIN, CHANGE R1, R2
USING THROUGH-HOLE PADS R1A, R2A
(SEE DATASHEET FOR VALUES)
SDN* = SHUTDOWN INPUT
< 2v = SHUTDOWN
VCC RANGE: 2.5V TO 5.5V
(COM-00906, COM-09940, COM-09119, COM-10613, ETC.)
KEEP SPEAKER LEADS
AS SHORT AS PRACTICAL
TO MINIMIZE 250KHz EMI

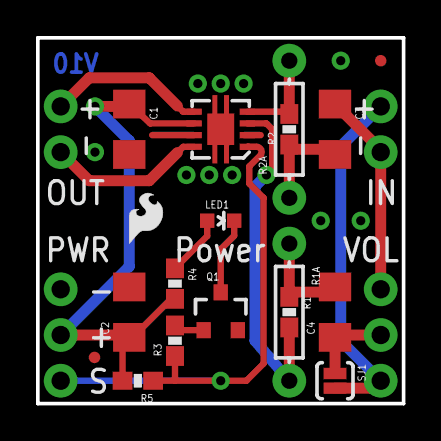
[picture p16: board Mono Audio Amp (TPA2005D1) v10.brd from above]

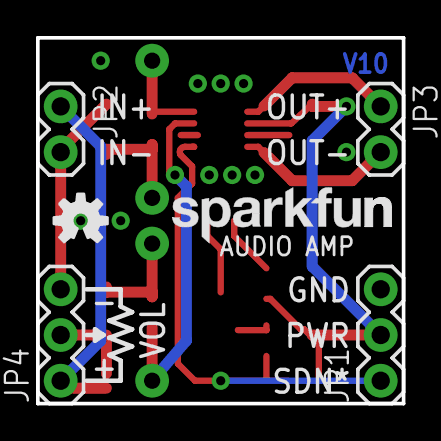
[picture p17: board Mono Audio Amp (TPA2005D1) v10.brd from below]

Board: 2 copper layers, 20.3 x 20.3 mm, 25 parts (6 on the bottom side), 15 nets.

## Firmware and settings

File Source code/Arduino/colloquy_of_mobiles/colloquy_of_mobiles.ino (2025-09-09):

#include <Adafruit_NeoPixel.h>
#include <ArduinoJson.h>
// Configuration des Neopixels pour chaque groupe
#define FEMALE1_NEOPIXEL_PIN 6
#define FEMALE2_NEOPIXEL_PIN 7
#define FEMALE3_NEOPIXEL_PIN 8
#define MALE1_BODY_NEOPIXEL_PIN 9
#define MALE2_BODY_NEOPIXEL_PIN 10
#define MALE1_UP_RING_NEOPIXEL_PIN 5
#define MALE2_UP_RING_NEOPIXEL_PIN 4

#define FEMALE_NUM_PIXELS 50             // Nombre de LEDs par groupe
#define MALE_BODY_NUM_PIXELS 40          // Nombre de LEDs par groupe
#define MALE_BODY_RING_END_PIXELS 24     // Nombre de LEDs par groupe
#define MALE_BODY_DRIVE_START_PIXELS 25  // Nombre de LEDs par groupe
#define MALE_UP_RING_NUM_PIXELS 12       // Nombre de LEDs par groupe

// Initialisation des bandes Neopixel
Adafruit_NeoPixel female1Strip(FEMALE_NUM_PIXELS, FEMALE1_NEOPIXEL_PIN, NEO_GRBW + NEO_KHZ800);
Adafruit_NeoPixel female2Strip(FEMALE_NUM_PIXELS, FEMALE2_NEOPIXEL_PIN, NEO_GRBW + NEO_KHZ800);
Adafruit_NeoPixel female3Strip(FEMALE_NUM_PIXELS, FEMALE3_NEOPIXEL_PIN, NEO_GRBW + NEO_KHZ800);
Adafruit_NeoPixel male1UpRingStrip(MALE_UP_RING_NUM_PIXELS, MALE1_UP_RING_NEOPIXEL_PIN, NEO_GRBW + NEO_KHZ800);
Adafruit_NeoPixel male1BodyStrip(MALE_BODY_NUM_PIXELS, MALE1_BODY_NEOPIXEL_PIN, NEO_GRBW + NEO_KHZ800);
Adafruit_NeoPixel male2UpRingStrip(MALE_UP_RING_NUM_PIXELS, MALE2_UP_RING_NEOPIXEL_PIN, NEO_GRBW + NEO_KHZ800);
Adafruit_NeoPixel male2BodyStrip(MALE_BODY_NUM_PIXELS, MALE2_BODY_NEOPIXEL_PIN, NEO_GRBW + NEO_KHZ800);

// Configuration des haut-parleurs pour chaque groupe
#define FEMALE1_SPEAKER_PIN 11
#define FEMALE2_SPEAKER_PIN 12
#define FEMALE3_SPEAKER_PIN 13
#define MALE1_SPEAKER_PIN 22
#define MALE2_SPEAKER_PIN 23

// Config for photosensors
#define FEMALE1_PHOTOSENSOR_PIN 59  // What is A5 pin number ?
#define FEMALE2_PHOTOSENSOR_PIN 60  // What is A6 pin number ?
#define FEMALE3_PHOTOSENSOR_PIN 61  // What is A7 pin number ?

void updateStrip(Adafruit_NeoPixel* strip, int numPixels, int r, int g, int b, int w, int brightness);

class PixelGroup {
public:
  Adafruit_NeoPixel* strip;
  int startPixel;
  int numPixels;
  uint8_t brightness = 255;  // propre au groupe

  PixelGroup(Adafruit_NeoPixel* strip, int startPixel, int numPixels)
    : strip(strip), startPixel(startPixel), numPixels(numPixels) {}

  void setBrightness(uint8_t b) {
    brightness = b;
  }

  String fill(JsonDocument& doc) {
    for (int i = startPixel; i < startPixel + numPixels; i++) {
      int r = doc["r"] | 0;
      int g = doc["g"] | 0;
      int b = doc["b"] | 0;
      int w = doc["w"] | 0;
      int brightness = doc["brightness"] | 255;
      setBrightness(brightness);
      strip->setPixelColor(i,
                           strip->Color(
                             scaleBrightness(r),
                             scaleBrightness(g),
                             scaleBrightness(b),
                             scaleBrightness(w)));
    }
    strip->show();
    return R"({"status": "success", "message": "Neopixel updated"})";
  }

  void clear() {
    for (int i = startPixel; i < startPixel + numPixels; i++) {
      strip->setPixelColor(i, 0);
    }
    strip->show();
  }

private:
  uint8_t scaleBrightness(uint8_t value) {
    return (uint16_t(value) * brightness) / 255;
  }
};

class Female {
public:
  String name;
  Adafruit_NeoPixel* strip;
  int speakerPin;
  // int numPixels;
  PixelGroup neopixel;

  Female(String name, Adafruit_NeoPixel* strip, int speakerPin, int numPixels)
    : name(name), neopixel(strip, 0, FEMALE_NUM_PIXELS), speakerPin(speakerPin) {}

  // String neopixel(JsonDocument& doc) {
  //   int r = doc["r"] | 0;
  //   int g = doc["g"] | 0;
  //   int b = doc["b"] | 0;
  //   int w = doc["w"] | 0;
  //   int brightness = doc["brightness"] | 255;

  //   updateStrip(strip, numPixels, r, g, b, w, brightness);
  //   return R"({"status": "success", "message": "Neopixel updated"})";
  // }

  String speaker(JsonDocument& doc) {
    String data = doc["data"];
    if (data == "on") {
      tone(speakerPin, 300);
    } else {
      noTone(speakerPin);
    }
    return R"({"status": "success", "message": "Speaker updated"})";
  }

  String sensor(int pin) {
    int value = analogRead(pin);
    String result = "{\"status\": \"success\", \"value\": ";
    result += value;
    result += "}";
    return result;
  }
};

class MaleBody {
public:
  Adafruit_NeoPixel* strip;
  // int numPixels;
  PixelGroup ring;
  PixelGroup drive;

  MaleBody(Adafruit_NeoPixel* strip)
    : ring(strip, 0, MALE_BODY_RING_END_PIXELS), drive(strip, MALE_BODY_DRIVE_START_PIXELS, MALE_BODY_NUM_PIXELS) {}
};

class Male {
public:
  String name;
  Adafruit_NeoPixel* bodyStrip;
  Adafruit_NeoPixel* upRingStrip;
  int speakerPin;
  // int numPixels;
  MaleBody body;
  PixelGroup upRing;

  Male(String name, Adafruit_NeoPixel* bodyStrip, Adafruit_NeoPixel* upRingStrip, int speakerPin)
    : name(name),
      upRing(upRingStrip, 0, MALE_UP_RING_NUM_PIXELS),
      speakerPin(speakerPin),
      body(bodyStrip),
      bodyStrip(bodyStrip),
      upRingStrip(upRingStrip) {}

  // String upRing(JsonDocument& doc) {
  //   int r = doc["r"] | 0;
  //   int g = doc["g"] | 0;
  //   int b = doc["b"] | 0;
  //   int w = doc["w"] | 0;
  //   int brightness = doc["brightness"] | 255;

  //   updateStrip(strip, numPixels, r, g, b, w, brightness);
  //   return R"({"status": "success", "message": "Neopixel updated"})";
  // }

  String speaker(JsonDocument& doc) {
    String data = doc["data"];
    if (data == "on") {
      tone(speakerPin, 300);
    } else {
      noTone(speakerPin);
    }
    return R"({"status": "success", "message": "Speaker updated"})";
  }
};

Female female1("female1", &female1Strip, FEMALE1_SPEAKER_PIN, FEMALE_NUM_PIXELS);
Female female2("female2", &female2Strip, FEMALE2_SPEAKER_PIN, FEMALE_NUM_PIXELS);
Female female3("female3", &female3Strip, FEMALE3_SPEAKER_PIN, FEMALE_NUM_PIXELS);
Male male1("male1", &male1BodyStrip, &male1UpRingStrip, MALE1_SPEAKER_PIN);
Male male2("male2", &male2BodyStrip, &male2UpRingStrip, MALE2_SPEAKER_PIN);

void setup() {
  // Initialisation des Neopixels
  female1Strip.begin();
  female2Strip.begin();
  female3Strip.begin();
  male1BodyStrip.begin();
  male2BodyStrip.begin();
  male1UpRingStrip.begin();
  male2UpRingStrip.begin();

  female1Strip.show();
  female2Strip.show();
  female3Strip.show();
  male1BodyStrip.show();
  male2BodyStrip.show();
  male1UpRingStrip.show();
  male2UpRingStrip.show();

  // Initialisation des haut-parleurs
  pinMode(FEMALE1_SPEAKER_PIN, OUTPUT);
  pinMode(FEMALE2_SPEAKER_PIN, OUTPUT);
  pinMode(FEMALE3_SPEAKER_PIN, OUTPUT);
  pinMode(MALE1_SPEAKER_PIN, OUTPUT);
  pinMode(MALE2_SPEAKER_PIN, OUTPUT);

  // Initialisation du port série
  Serial.begin(57600);
  // Each time the serial port is opened the Arduino is rebooted.
  // The arduino will be ready when client can read "Hello!" on the serial.
  Serial.println("Hello!");
}

void loop() {
  if (Serial.available()) {
    String input = Serial.readStringUntil('\n');  // Lire la commande
    String response = processCommand(input);      // Traiter la commande
    Serial.println(response);                     // Répondre au PC
  }
}

String processCommand(const String& input) {
  // Analyse du JSON
  StaticJsonDocument<256> jsonDoc;
  DeserializationError error = deserializeJson(jsonDoc, input);
  if (error) {
    return R"({"status": "error", "message": "Invalid JSON"})";
  }

  if (!jsonDoc.containsKey("path")) return R"({"status": "error", "message": "Missing path"})";

  String path = jsonDoc["path"];

  if (path == "female1/speaker") {
    return female1.speaker(jsonDoc);
  } else if (path == "female1/neopixel") {
    return female1.neopixel.fill(jsonDoc);
  } else if (path == "female2/speaker") {
    return female2.speaker(jsonDoc);
  } else if (path == "female2/neopixel") {
    return female2.neopixel.fill(jsonDoc);
  } else if (path == "female3/speaker") {
    return female3.speaker(jsonDoc);
  } else if (path == "female3/neopixel") {
    return female3.neopixel.fill(jsonDoc);
  } else if (path == "male1/speaker") {
    return male1.speaker(jsonDoc);
  } else if (path == "male1/up_ring") {
    return male1.upRing.fill(jsonDoc);
  } else if (path == "male1/body/drive") {
    return male1.body.drive.fill(jsonDoc);
  } else if (path == "male1/body/ring") {
    return male1.body.ring.fill(jsonDoc);
  } else if (path == "male2/speaker") {
    return male2.speaker(jsonDoc);
  } else if (path == "male2/up_ring") {
    return male2.upRing.fill(jsonDoc);
  } else if (path == "male2/body/drive") {
    return male2.body.drive.fill(jsonDoc);
  } else if (path == "male2/body/ring") {
    return male2.body.ring.fill(jsonDoc);
  } else if (path == "female1/sensor") {
    return female1.sensor(FEMALE1_PHOTOSENSOR_PIN);
  } else if (path == "female2/sensor") {
    return female2.sensor(FEMALE2_PHOTOSENSOR_PIN);
  } else if (path == "female3/sensor") {
    return female3.sensor(FEMALE3_PHOTOSENSOR_PIN);
  }


  return R"({"status": "error", "message": "Invalid path or data"})";
}

void updateStrip(Adafruit_NeoPixel* strip, int numPixels, int r, int g, int b, int w, int brightness) {
  strip->setBrightness(brightness);
  for (int i = 0; i < numPixels; i++) {
    strip->setPixelColor(i, strip->Color(r, g, b, w));
  }
  strip->show();
}

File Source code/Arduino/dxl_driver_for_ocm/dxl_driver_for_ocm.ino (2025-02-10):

#include <Dynamixel2Arduino.h>

#define DEBUG_SERIAL Serial
#define DXL_SERIAL Serial1
#define BAUDRATE 57600

using namespace ControlTableItem;

const int DXL_DIR_PIN = 28;
Dynamixel2Arduino dxl(DXL_SERIAL, DXL_DIR_PIN);
unsigned long last_log = 0; // Initialize last_log variable

void setup() {
  DEBUG_SERIAL.begin(57600);
  dxl.setPortProtocolVersion(2.0f);
  dxl.begin(57600);
}

void loop() {
  // Get the first word
  // DEBUG_SERIAL.println("Waiting for command.");
  String command = readWord();
  if (command == "ping") {
    handlePing();
  }
  if (command == "set") {
    handleSet();
  }
  if (command == "get") {
    handleGet();
  }

  // Flush the serial buffer
  while (Serial.available()) {
    Serial.read();
  }
  // Add more cases for other commands as needed

  // dxl.writeControlTableItem(TORQUE_ENABLE, 1, 1);
}

void handleSet() {
  String property = readWord();
  if (property == "drive_mode") {
    handleSetDriveMode();
  }
  if (property == "torque_enable") {
    handleSetTorqueEnable();
  }
  if (property == "profile_velocity") {
    handleSetProfileVelocity();
  }
  if (property == "profile_acceleration") {
    handleSetProfileAcceleration();
  }
  if (property == "goal_position") {
    handleSetGoalPosition();
  }
}

void handleSetGoalPosition() {
  int id = readWord().toInt();
  int value = readWord().toInt();
  int result = dxl.writeControlTableItem(GOAL_POSITION, id, value);
  DEBUG_SERIAL.println(result);
}

void handleSetProfileAcceleration() {
  int id = readWord().toInt();
  int value = readWord().toInt();
  int result = dxl.writeControlTableItem(PROFILE_ACCELERATION, id, value);
  DEBUG_SERIAL.println(result);
}

void handleSetProfileVelocity() {
  int id = readWord().toInt();
  int value = readWord().toInt();
  int result = dxl.writeControlTableItem(PROFILE_VELOCITY, id, value);
  DEBUG_SERIAL.println(result);
}


void handleSetTorqueEnable() {
  int result;
  int id = readWord().toInt();
  int value = readWord().toInt();
  if (value == 0){
    result = dxl.torqueOff(id);
    }
  if (value == 1){
    result = dxl.torqueOn(id);
    }
  //int result = dxl.writeControlTableItem(TORQUE_ENABLE, id, value);
  DEBUG_SERIAL.println(result);
}

void handleSetDriveMode() {
  int id = readWord().toInt();
  int value = readWord().toInt();
  int result = dxl.writeControlTableItem(DRIVE_MODE, id, value);
  DEBUG_SERIAL.println(result);
}

void handleGet() {
  String property = readWord();
  if (property == "drive_mode") {
    handleGetDriveMode();
  }
  if (property == "temperature") {
    handleGetTemperature();
  }
  if (property == "elec_current") {
    handleGetElecCurrent();
  }
  if (property == "torque_enable") {
    handleGetTorqueEnable();
  }
  if (property == "profile_velocity") {
    handleGetProfileVelocity();
  }
  if (property == "profile_acceleration") {
    handleGetProfileAcceleration();
  }
  if (property == "goal_position") {
    handleGetGoalPosition();
  }
  if (property == "position") {
    handleGetPosition();
  }
}

void handleGetPosition() {
  int id = readWord().toInt();
  DEBUG_SERIAL.println(dxl.readControlTableItem(PRESENT_POSITION, id));
}

void handleGetGoalPosition() {
  int id = readWord().toInt();
  DEBUG_SERIAL.println(dxl.readControlTableItem(GOAL_POSITION, id));
}

void handleGetProfileAcceleration() {
  int id = readWord().toInt();
  DEBUG_SERIAL.println(dxl.readControlTableItem(PROFILE_ACCELERATION, id));
}

void handleGetProfileVelocity() {
  int id = readWord().toInt();
  DEBUG_SERIAL.println(dxl.readControlTableItem(PROFILE_VELOCITY, id));
}

void handleGetTorqueEnable() {
  int id = readWord().toInt();
  DEBUG_SERIAL.println(dxl.readControlTableItem(TORQUE_ENABLE, id));
}


void handleGetElecCurrent() {
  int id = readWord().toInt();
  DEBUG_SERIAL.println(dxl.readControlTableItem(PRESENT_CURRENT, id));
}

void handleGetTemperature() {
  int id = readWord().toInt();
  DEBUG_SERIAL.println(dxl.readControlTableItem(PRESENT_TEMPERATURE, id));
}


void handleGetDriveMode() {
  int id = readWord().toInt();
  DEBUG_SERIAL.println(dxl.readControlTableItem(DRIVE_MODE, id));
}

void handlePing() {
  String string_id = readWord();
  int id = string_id.toInt();
  DEBUG_SERIAL.println(dxl.ping(id));
}

String readWord() {
  String command = "";
  char letter;

  while (true) {
    if (Serial.available()) {
      letter = Serial.read();
      if (letter == ' ') {
        return command;
      }
      if (letter == '\n') {
        return command;
      }
      command += letter;
    }
  }
}

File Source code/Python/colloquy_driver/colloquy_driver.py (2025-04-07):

from .dynamixel_manager import DynamixelManager
from .arduino_manager import ArduinoManager
from .female_driver import FemaleDriver
from .male_driver import MaleDriver
from .bar_driver import BarDriver
from .logger import Logger
from .thread_driver import ThreadDriver
from time import sleep
from parameters import Parameters
from threading import Thread, Event

class ColloquyDriver(ThreadDriver):

    _classes = {
        "dxl_manager": DynamixelManager,
        "arduino_manager": ArduinoManager,
        "female_driver": FemaleDriver,
        "male_driver": MaleDriver,
        "bar_driver": BarDriver,
    }

    def __init__(self, params, name="Colloquy driver"):
        print(f"Initialising {name}...")
        self._is_open = False
        self._name = name
        self.mirrors = []
        self.males = []
        self.bodies = []
        self.elements = []
        self.bar = None
        self._stop_event = Event()
        self._threads = set()
        self.females = []
        self.males = []
        self._arduino_manager = arduino_manager = None
        self._dxl_manager = dxl_manager = None


        dxl_manager_params = params["dynamixel network"]
        dxl_manager_params["name"] = "dxl_driver"
        self._dxl_manager = dxl_manager = self._classes["dxl_manager"](**dxl_manager_params)

        arduino_params = params["arduino"]
        arduino_params["name"] = "arduino_driver"
        self._arduino_manager = arduino_manager = self._classes["arduino_manager"](**arduino_params)

        self._init_females(params)
        self._init_males(params)

        # Defined at for each bar position, which female and male interacts
        self.nearby_interactions = {
            0: NearbyInteractions(self.male2, self.female1),
            1600: NearbyInteractions(self.male1, self.female3),
            3900: NearbyInteractions(self.male2, self.female2),
            6500: NearbyInteractions(self.male1, self.female1),
            7900: NearbyInteractions(self.male2, self.female3),
            10200: NearbyInteractions(self.male1, self.female2),
        }

        self._init_bar(params)

        self.bodies = [
            *self.females,
            *self.males,
            ]


        self.elements = [
            *self.females,
            *self.mirrors,
            *self.males,
            self.bar
        ]

    @property
    def stop_event(self):
        return self._stop_event

    @property
    def arduino(self):
        return self._arduino_manager

    @property
    def nearby_interaction(self):
        return self.bar.nearby_interaction

    def _init_bar(self, params):
        bar_params = dict(params["bar"])
        bar_params["colloquy"] = self
        bar_params["name"] = "bar"
        bar_params["dynamixel manager"] = self._dxl_manager
        bar_params["colloquy"] = self
        if bar_params["origin"] is not None:
            self.bar = self._classes["bar_driver"](owner=self, **bar_params)

    def _init_females(self, params, ):
        females_params = params["females"]
        females_names = females_params["names"]
        for name in females_names:
            fem_params = dict(params[name])
            fem_params["name"] = name
            fem_params.update( params["females"]["share"])
            fem_params["dynamixel manager"] = self._dxl_manager
            fem_params["arduino manager"] = self._arduino_manager
            fem_params["colloquy"] = self
            female_driver = self._classes["female_driver"](owner=self, **fem_params)
            self.females.append(female_driver)
            setattr(self, name, female_driver)
            self.mirrors.append(female_driver.mirror)

    def _init_males(self, params, ):
        males_params = params["males"]
        males_names = males_params["names"]
        for name in males_names:
            male_params = dict(params[name])
            male_params["name"] = name
            male_params.update( params["males"]["share"])
            male_params["dynamixel manager"] = self._dxl_manager
            male_params["arduino manager"] = self._arduino_manager
            male_params["colloquy"] = self
            male_driver = self._classes["male_driver"](owner=self, **male_params)
            self.males.append(male_driver)
            setattr(self, name, male_driver)

    def turn_to_origin_position(self, elements):
        for element in elements:
            element.turn_to_origin_position()

    def turn_to_max_position(self, elements):
        for element in elements:
            element.turn_to_max_position()

    def turn_to_min_position(self, elements):
        for element in elements:
            element.turn_to_min_position()

    def turn_on_neopixel(self, elements):
        for element in elements:
            element.turn_on_neopixel()

    def turn_off_neopixel(self, elements):
        for element in elements:
            element.turn_off_neopixel()

    def is_something_moving(self):
        return any(
            (e.is_moving
            for e
            in self.elements)
        )

    def wait_until_everything_is_still(self):
        print(f"Waiting until everything is stopped...")
        while self.is_something_moving():
            sleep(0.1)

    # def calibrate(self):
        # import code
        # colloquy = self
        # locals_dict = {
            # "female1": self.female1,
            # "female2": self.female2,
            # "female3": self.female3,
            # "mirror1": self.female1.mirror,
            # "mirror2": self.female2.mirror,
            # "mirror3": self.female3.mirror,
            # "male1": self.male1,
            # "male2": self.male2,
            # }

        # code.interact(local=locals_dict, banner=CALIBRATION_BANNER)

    def run(self):
        print(f"Running {self._name}...")
        self.stop_event.clear()
        for element in self.elements:
            element.turn_to_origin_position()
        self.wait_until_everything_is_still()

        for body in self.bodies:
            thread = Thread(target=body.run, name=body.name)
            self._threads.add(thread)
            thread.start()

        raise NotImplementedError(f"Move the thread start into in the run element.")
        raise NotImplementedError(f"Remove the self._threads attribute.")
        thread = Thread(target=self.bar.run, name="bar")
        self._threads.add(thread)
        thread.start()

        while not self.stop_event.is_set():
            self.sleep_min()

        for element in self.elements:
            element.stop_event.set()

        raise NotImplementedError(f"Stop the bodies directly.")
        for thread in self._threads:
            thread.join()

    def start(self):
        self.stop_event.clear()
        self.thread = Thread(target=self.run, name=self._name)
        self.thread.start()

    def stop(self):
        if self.stop_event.is_set():
            return
        self.stop_event.set()
        self.thread.join()
        self.thread = None
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

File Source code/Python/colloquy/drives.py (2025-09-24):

from time import time
from threading import Lock
from colloquy.thread_element import ThreadElement

"""logic35_systems.ino
//act_drive
const int   internal_drive_LL = 600;      //interested floor, in samples     600 = 30 seconds
const int   internal_drive_UL = 3600;     //desperate floor, in samples     3600 = 3 minutes
const int   internal_drive_MAX = 4800;    //in samples                      4800 = 4 minutes
const int   internal_drive_adjustment_O = 1;
const int   internal_drive_adjustment_P  = 1;
int         internal_drive_O = 0;
int         internal_drive_P = 0;
int         internal_drive_state = 0;     //Undefined, Neither[Inert], O, P, OP
"""

class Drives(ThreadElement):

    def __init__(self, owner, neopixel):
        name = f"{owner.name}_drives"
        ThreadElement.__init__(self, name=name, owner=owner)
        self._neopixel = neopixel
        self._o_drive = 0
        self._p_drive = 0
        self._update_interval = 2
        self._timestamp = time()

        self._step_o = 2
        self._step_p = 3

        self._max = 255
        self._min = 0

        self._satisfaction_lim = 10
        self._frustrated_lim = 235

        self._lock = Lock()

        self._orange = dict(red=255, green=165, blue=0, white=0)
        self._white = dict(red=0, green=0, blue=0, white=255)
        self._puce = dict(red=80, green=53, blue=60, white=125) #CC8899
        self._colors = {
            ("O",): self._orange,
            ("P",): self._puce,
            tuple(): self._puce,
            ("O", "P",): self._puce,
        }

    def __getitem__(self, key):
        for_max = list()
        with self._lock:
            if not key:
                return  max(self.o_drive, self.p_drive)

            if "O" in key:
                for_max.append(self.o_drive)
            if "P" in key:
                for_max.append(self.p_drive)
            return max(for_max)

    @property
    def puce(self):
        return self._puce

    @property
    def orange(self):
        return self._orange

    @property
    def white(self):
        return self._white

    @property
    def color(self):
        return self._colors[self.state]

    @property
    def value(self):
        state = self.state
        return state, self[state], self._colors[state]

    @property
    def state(self):
        # raise NotImplementedError(f"Update to return a tuple for the states")
        with self._lock:
            o_satisfaction_lim = self.o_drive < self._satisfaction_lim
            p_satisfaction_lim = self.p_drive < self._satisfaction_lim
            o_frustated = self.o_drive > self._frustrated_lim
            p_frustated = self.p_drive > self._frustrated_lim

            if o_satisfaction_lim and p_satisfaction_lim:
                return tuple()
            if o_frustated and p_frustated:
                return ("O", "P")
            if self.o_drive > self.p_drive:
                assert not o_satisfaction_lim
                return ("O", )
            if self.p_drive > self.o_drive:
                assert not p_satisfaction_lim
                return ("P", )
            if self.p_drive == self.o_drive:
                return ("O", "P")

            raise ValueError(f"Drive Error, {self.o_drive=}, {self.p_drive=}")

    @property
    def max(self):
        return self._max

    @property
    def o_drive(self):
        return self._o_drive

    @o_drive.setter
    def o_drive(self, value):
        assert isinstance(value, int)
        self._o_drive = value
        self._update_neopixel()

    @property
    def p_drive(self):
        return self._p_drive

    @p_drive.setter
    def p_drive(self, value):
        assert isinstance(value, int)
        self._p_drive = value
        self._update_neopixel()

    @property
    def is_unsatisfied(self):
        raise NotImplementedError(f"Use is_frustrated_lim instead!")
        return bool(self.state)

    @property
    def is_frustated(self):
        return bool(self.state)

    @property
    def satisfaction_lim(self):
        return self._satisfaction_lim

    def __enter__(self):
        """Setup before loop."""
        self.stop_event.clear()

    def __exit__(self, exc_type, exc_value, traceback_obj):
        if self.owner.search.is_started:
            self.owner.search.stop()
        return ThreadElement.__exit__(self, exc_type, exc_value, traceback_obj)

    def _loop(self):
        if time() - self._timestamp < self._update_interval:
            return
        self._timestamp = time()
        self._update()

    def _setup(self, **kwargs):
        self._neopixel.on()

    def _update(self):
        self.o_drive += self._step_o
        self.p_drive += self._step_p
        if self.o_drive > self._max:
            self.o_drive = self._max
        if self.p_drive > self._max:
            self.p_drive = self._max

        self._update_neopixel()


        if self.is_frustated:
            if not self.owner.search.is_started:
                self.owner.search.start()
            return

    def decrease(self, drive):
        if "O" in drive:
            self.o_drive -= 20 * self._step_o
        if "P" in drive:
            self.p_drive -= 20 * self._step_p
        self._update_neopixel()

    def is_satisfied(self, drive):
        satisfied_drives = []
        for value in drive:
            if value == "O":
                is_satisfied = self.o_drive < self._satisfaction_lim
                satisfied_drives.append(is_satisfied)
            if "P" in drive:
                is_satisfied = self.p_drive < self._satisfaction_lim
                satisfied_drives.append(is_satisfied)
                

        return all(satisfied_drives)


    def satisfy(self):
        self.o_drive = self._satisfaction_lim
        self.p_drive = self._satisfaction_lim

    def _update_neopixel(self):
        state, brightness, color = self.value
        
        # Trying to reduce brigtness to avoid blink
        # Look like when the RGB value are all 255, the white LED is turned on, and RGB LEDs turned off. If white value is 0 then everything is turn off.
        if brightness > 254:
            brightness = 254
            
        config = dict(
            brightness = brightness,
            **color,
            )
        self._neopixel.configure(**config)
    
    def _set_p_drive(self, **kwargs):
        value = kwargs["value"][0]
        self._p_drive = int(value)
        
    def _set_o_drive(self, **kwargs):
        value = kwargs["value"][0]
        self._o_drive = int(value)
        # raise NotImplementedError(f"{kwargs=}, {self.post_data=}")
        

    def add_html(self):
        doc, tag, text = self.html_doc.tagtext()

        with tag("h4"):
            text(f"Drives:")
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

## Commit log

2025-02-17 Setup virtual drivers.
    The virtual driver will be use to test code without the hardware.
2025-02-17 Implement the male blinking.
    Yet to be tested.
    [video analysis.blend]
2025-02-18 Setup mouvement cycle for males and females.
    [video analysis.blend]
2025-02-18 Implemented thread locks.
2025-02-18 Change prints.
2025-02-27 Blank changes.
    [video analysis.blend]
2025-03-06 Add longer min sleep to leave CPU.
    Clean prints
2025-03-10 Implement the search thread.
2025-03-13 Implemented calibration commands
2025-03-13 Fix dxl origin for bar positions
    [bar_driver.py]
2025-03-27 Update calibration.
    Implement setting Nopixel colors.
2025-04-01 Update colloquy driver.
    Arduino:
    - Set up drive neopixel
    Python:
    - Set up logger.
2025-04-01 Fix light pattern issue.
    [body.py, colloquy_driver.py, female_driver.py]
2025-04-01 Fixed male drive blinking.
    [colloquy_driver.py, colloquy_of_mobiles.ino]
2025-04-01 Reset drive after interaction.
    [colloquy_of_mobiles.ino, drives_handler.py, female_driver.py]
2025-04-03 Setup Mirrors behaviour.
    - Clean up the open behaviour.
    - Remove the logger thread.
    -
2025-04-07 Setting up the mirror thread.
2025-04-07 Updated virtual dxl drivers.
2025-04-24 Prototype mirror exposition.
2025-04-24 FIx partially calibration.
2025-04-24 Continue fixing the calibration.
    [arduino_manager.py]
2025-04-24 Fix configuration for Neopixels.
    [bar_driver.py, body.py, neopixel.py]
2025-04-29 Update arduino and fixed calibration.
    [arduino_manager.py, colloquy.py, colloquy_of_mobiles.ino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]
2025-05-13 Remove code for virtual driver.
2025-05-13 Change color and fix male blinking.
    [drives_handler.py]
2025-05-14 Implement male/search
    [questions.xlsx]
2025-05-14 Set up search male thread.
    [questions.xlsx]
2025-05-14 Implement female search
    [questions.xlsx]
2025-05-14 Clean up.
    [questions.xlsx]
2025-05-15 Implement interaction.
    [questions.xlsx, scenarios.blend]
2025-05-20 Set up test framework.
    [questions.xlsx, scenarios.blend]
2025-05-28 Implemented interaction.
    [questions.xlsx]
2025-05-30 Try remove error offset
    [colloquy.py]
2025-06-12 Implement base test for power consumption.
2025-06-12 Implement power consumption test.
2025-06-30 Update electronic box PCB
    [Mono Audio Amp (TPA2005D1) v10.brd, Mono Audio Amp (TPA2005D1) v10.sch, center edge cut.FCStd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]
2025-07-03 Redesign main PCB.
    [electronic box.kicad_pcb, electronic box.kicad_sch]
2025-08-05 Fixing UI
    [electronic box-B_Cu.gbr, electronic box-B_Mask.gbr, electronic box-B_Paste.gbr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]
2025-09-01 Fixed pins for the male speaker.
    [colloquy_of_mobiles.ino, drives.py]
2025-09-02 Fix ring pin number
    [colloquy_of_mobiles.ino]
2025-09-09 Implemented test female1 photo sensor.
2025-09-19 Debug threading.

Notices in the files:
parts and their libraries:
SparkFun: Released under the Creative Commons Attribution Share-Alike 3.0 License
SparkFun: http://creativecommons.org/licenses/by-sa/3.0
